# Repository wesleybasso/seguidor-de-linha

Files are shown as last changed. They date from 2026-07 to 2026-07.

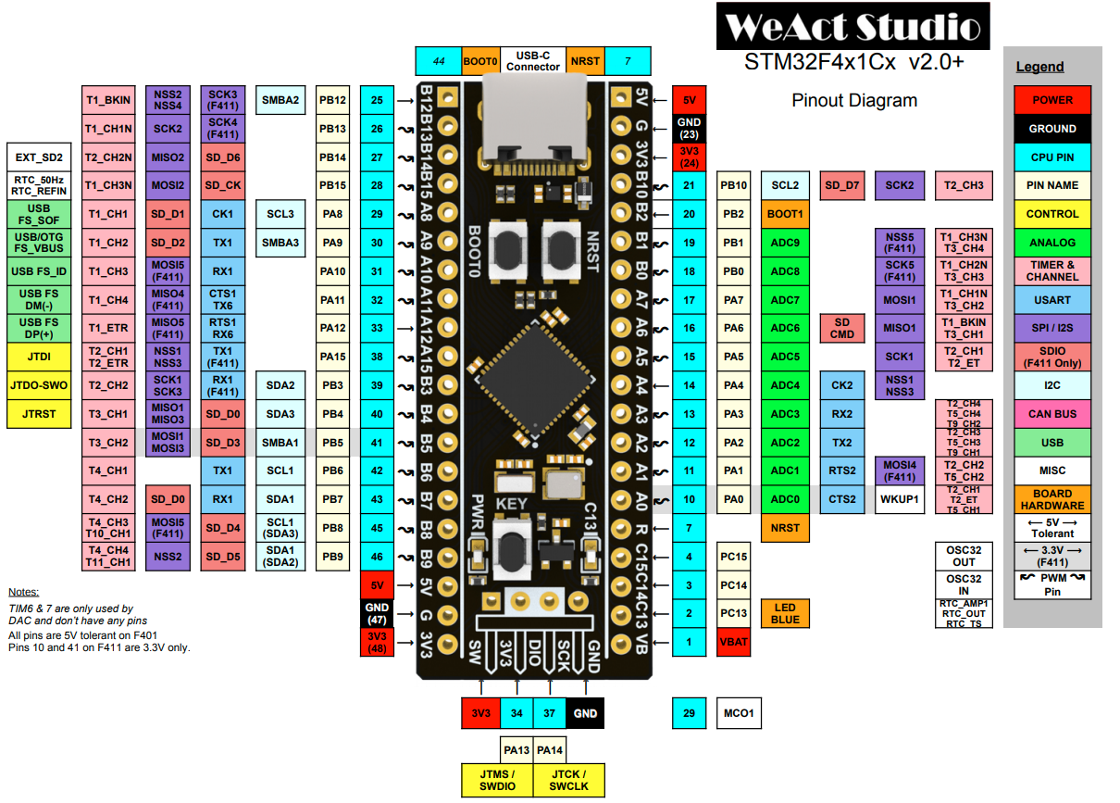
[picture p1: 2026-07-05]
STM32F411CE-Black-Pill-Board-Pinout-Diagram.png

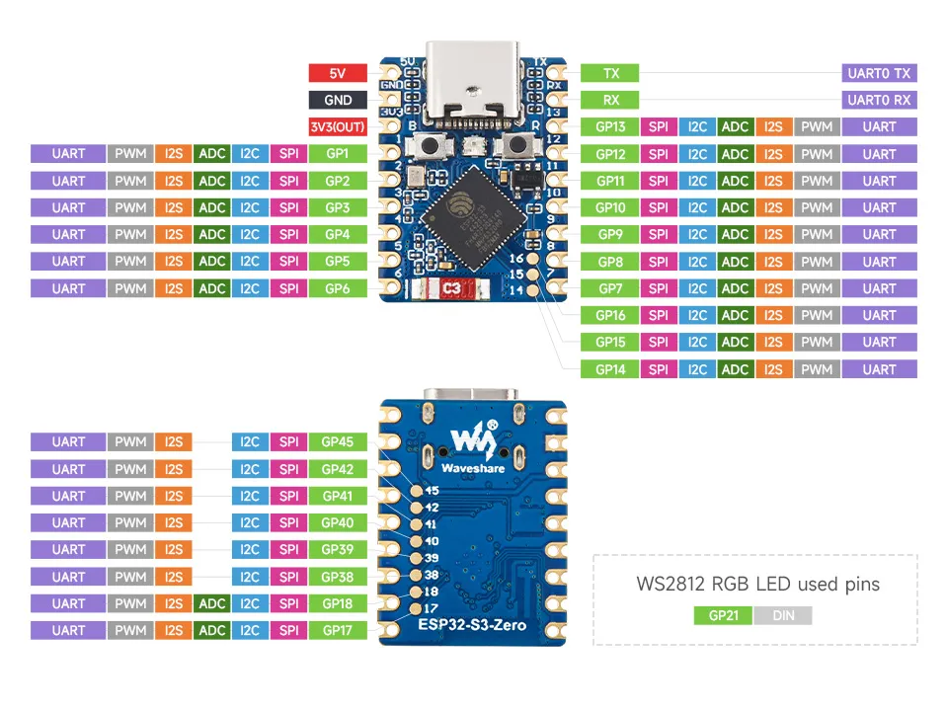
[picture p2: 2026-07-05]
ESP32-S3-Zero pin.png

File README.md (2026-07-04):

# PEGASUS Rev A0

PEGASUS e um robo seguidor de linha modular em tres placas.

- `HDB-001` Brain Board: Black Pill STM32F411, XIAO ESP32-S3/Plus, debug e conectores para o chassi.
- `HDB-100` Chassis / Power Board: LiPo 2S, chave, TB6612FNG, buck 5V, motores e succao central.
- `HDB-101` Sensor Board: placa frontal/adaptadora para sensor vermelho de 8 canais na Rev A0.

## Estrutura

- `kicad documents/`: projetos KiCad e biblioteca local de footprints placeholder.
- `docs/`: requisitos, pinagem e decisoes de engenharia.
- `firmware/`: requisitos iniciais de firmware STM32/ESP32 e protocolo UART.
- `manufacturing/`: checklist preliminar JLCPCB/PCBWay.
- `sketches/`: desenhos de arquitetura e mecanica.

## Estado Atual

Base mecanica KiCad Rev A0 criada. Ainda nao ha roteamento final, ERC/DRC final, nem Gerbers de fabricacao.

Nao enviar para fabricacao sem revisar:

- footprints reais com paquimetro;
- pinagem real da Black Pill, XIAO e modulo TB6612;
- corrente dos motores e succao;
- espacamento de bateria, motores, ventosa e empilhamento;
- DRC/ERC completo apos esquematicos e roteamento.

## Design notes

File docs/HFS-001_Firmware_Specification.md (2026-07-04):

# HFS-001 — Firmware Specification

Projeto: PEGASUS  
Revisão: A0

## 1. STM32F411

Responsável por:

- leitura A0–A7;
- leitura laterais;
- cálculo da posição da linha;
- PID;
- controle TB6612;
- controle FAN_PWM;
- comunicação UART;
- estado de segurança.

Estados:

- BOOT
- IDLE
- CALIBRATION
- READY
- RUN
- ERROR
- SAFE_STOP

## 2. ESP32-S3

Responsável por:

- telemetria;
- interface web futura;
- configuração de PID;
- log;
- comunicação USB/Wi-Fi/BLE.

Não deve controlar motores em tempo real.

## 3. Frequências sugeridas

- ADC: >= 1 kHz.
- PID: >= 1 kHz.
- Telemetria: 20–100 Hz.
- PWM motor: 20–50 kHz.
- PWM sucção:
  - MOSFET: 10–25 kHz.
  - ESC: sinal compatível com servo/ESC.

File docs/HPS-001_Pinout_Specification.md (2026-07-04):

# HPS-001 — Pinout Specification

Projeto: PEGASUS  
Revisão: A0

## 1. STM32F411 — Black Pill

### Sensores centrais

| Sinal | Pino STM32 | Função |
|---|---|---|
| A0 | PA0 | Sensor central 0 |
| A1 | PA1 | Sensor central 1 |
| A2 | PA2 | Sensor central 2 |
| A3 | PA3 | Sensor central 3 |
| A4 | PA4 | Sensor central 4 |
| A5 | PA5 | Sensor central 5 |
| A6 | PA6 | Sensor central 6 |
| A7 | PA7 | Sensor central 7 |

### Sensores laterais

| Sinal | Pino STM32 | Função |
|---|---|---|
| LAT_L | PB0 | Sensor lateral esquerdo |
| LAT_R | PB1 | Sensor lateral direito |

Observação:
Com A0–A7 + LAT_L + LAT_R, os canais ADC práticos ficam ocupados.  
Medição de bateria deve ser opcional por divisor no ESP32, ADC externo ou multiplexação futura.

### TB6612

| Sinal | Pino STM32 | Função |
|---|---|---|
| PWMA | PB8 | PWM motor esquerdo |
| AIN1 | PB10 | Direção motor esquerdo 1 |
| AIN2 | PB11 | Direção motor esquerdo 2 |
| PWMB | PB9 | PWM motor direito |
| BIN1 | PB12 | Direção motor direito 1 |
| BIN2 | PB13 | Direção motor direito 2 |
| STBY | PB14 | Standby TB6612 |

### Sucção

| Sinal | Pino STM32 | Função |
|---|---|---|
| FAN_PWM | PA8 | PWM sucção / ESC |

### UART STM32 ↔ ESP32

| Sinal | Pino STM32 |
|---|---|
| STM32_TX | PA9 |
| STM32_RX | PA10 |

Adicionar resistores série de 47Ω, se possível.

### SWD

| Função | Pino |
|---|---|
| SWDIO | PA13 |
| SWCLK | PA14 |
| NRST | NRST |
| 3V3 | 3V3 |
| GND | GND |

## 2. J1 — Brain ↔ Chassis — Sensores/Lógica

Tipo sugerido: 2x6 2.54 mm board-to-board.

| Pino | Sinal |
|-----:|---|
| 1 | 3V3 |
| 2 | GND |
| 3 | A0 |
| 4 | A1 |
| 5 | A2 |
| 6 | A3 |
| 7 | A4 |
| 8 | A5 |
| 9 | A6 |
| 10 | A7 |
| 11 | LAT_L |
| 12 | LAT_R |

## 3. J2 — Brain ↔ Chassis — Comandos/Potência

Tipo sugerido: 2x6 2.54 mm board-to-board.

| Pino | Sinal |
|-----:|---|
| 1 | VBAT_ADC opcional |
| 2 | GND |
| 3 | 5V_IN |
| 4 | GND |
| 5 | PWMA |
| 6 | AIN1 |
| 7 | AIN2 |
| 8 | PWMB |
| 9 | BIN1 |
| 10 | BIN2 |
| 11 | STBY |
| 12 | FAN_PWM |

## 4. Pendências

- Confirmar modelo exato do XIAO.
- Confirmar pinagem real do módulo TB6612.
- Definir medição de bateria.
- Definir se laterais serão analógicos ou digitais.

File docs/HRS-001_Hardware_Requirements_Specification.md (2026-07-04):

# HRS-001 — Hardware Requirements Specification

Projeto: PEGASUS  
Revisão: A0

## 1. Visão geral

O hardware é dividido em três placas:

- HDB-001 Brain Board.
- HDB-100 Chassis / Power Board.
- HDB-101 Sensor Board.

## 2. HDB-001 — Brain Board

### Função

Placa superior de lógica, controle, comunicação e debug.

### Componentes

- Black Pill STM32F411CEU6 plugável.
- XIAO ESP32-S3 ou XIAO ESP32-S3 Plus plugável.
- LEDs de status.
- Botões de boot/reset.
- Header SWD.
- Header UART debug.
- Conectores J1/J2 para chassi.
- Buck local opcional apenas para uso standalone.

### Não incluir

- TB6612.
- Motores.
- XT30.
- MOSFET de alta corrente.
- Capacitores grandes de potência.

## 3. HDB-100 — Chassis / Power Board

### Função

Placa inferior estrutural e de potência.

### Componentes

- XT30 para LiPo 2S.
- Chave geral ou chave de lógica.
- Capacitores bulk.
- Buck 5V.
- TB6612FNG.
- Conectores dos motores.
- Conector/área para sucção central.
- Furo/duto de sucção.
- Conectores J1/J2 para Brain Board.
- Conexão para Sensor Board.

## 4. HDB-101 — Sensor Board

### Função

Placa frontal de sensores.

### Rev A0

Pode ser interface para sensor comercial existente.

### Futuro

Sensor Board própria com sensores IR, resistores, filtros e conectores.

## 5. Alimentação

- Entrada: LiPo 2S.
- VBAT/VMOTOR: motores e sucção.
- 5V: lógica e Brain Board.
- 3V3: sensores e sinais lógicos.

## 6. Requisitos de segurança

- Todos os GNDs em comum.
- Corrente alta não deve passar pela Brain Board.
- Trilhas de potência largas.
- Capacitores próximos do TB6612, buck e entrada.
- Sinais analógicos afastados de motor/buck.
- Usar test points para sinais críticos.

## 7. Fabricação

- FR4.
- 1.6 mm.
- 2 camadas na Rev A0.
- Cobre 1 oz.
- Montagem manual possível.
- Silkscreen claro.

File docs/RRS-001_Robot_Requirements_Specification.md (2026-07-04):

# RRS-001 — Robot Requirements Specification

Projeto: PEGASUS  
Revisão: A0  
Autor: Wesley Mateus Basso / Hander

## 1. Objetivo

Definir os requisitos do robô antes do desenvolvimento detalhado das PCBs.

## 2. Arquitetura física

O robô usa dois andares:

- **Andar inferior:** HDB-100 Chassis / Power Board.
- **Andar superior:** HDB-001 Brain Board.
- **Frente:** HDB-101 Sensor Board.

A PCB inferior deve funcionar como parte estrutural do chassi.

## 3. Formato

O robô deve ser alongado, inspirado em seguidores de linha competitivos.

Características:

- frente estreita com régua de sensores;
- corpo central/traseiro largo;
- motores nas laterais;
- bateria baixa e centralizada;
- sucção central;
- Brain Board empilhada acima da região de controle.

## 4. Componentes mecânicos/eletrônicos principais

### Motores

- Tipo: N20.
- Rotação: 1000 rpm.
- Tensão nominal: 6V.
- Encoder: não, na Rev A0.

### Bateria

- Tipo: LiPo 2S.
- Tensão nominal: 7.4V.
- Tensão cheia: 8.4V.
- Capacidade sugerida: 450 a 850 mAh.
- Capacidade final: pendente.

### Sucção

- Um motor de sucção central.
- Tipo ainda indefinido.
- A placa deve suportar:
  - motor DC via MOSFET; ou
  - EDF/brushless via ESC.

### Sensores

- Sensor frontal vermelho tipo QTR/HY-S301/8 canais.
- Entradas A0–A7.
- Sensores laterais unitários já comprados.

## 5. Objetivos de firmware

- Loop PID: >= 1 kHz.
- Leitura de sensores: >= 1 kHz.
- PWM motores: 20 a 50 kHz se possível.
- Comunicação STM32 ↔ ESP32 por UART.
- ESP32 não deve ser necessário para o robô competir.

## 6. Prioridades

1. Funcionar.
2. Ser barato.
3. Ser fácil de consertar.
4. Validar firmware.
5. Validar mecânica.
6. Depois integrar e miniaturizar.

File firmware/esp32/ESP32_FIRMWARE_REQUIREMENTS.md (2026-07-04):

# ESP32-S3 Firmware Requirements

## Mínimo

- UART com STM32.
- Serial USB.
- Start/Stop.
- Ajuste PID.
- Telemetria.

## Futuro

- Interface web.
- BLE.
- OTA.
- Log.

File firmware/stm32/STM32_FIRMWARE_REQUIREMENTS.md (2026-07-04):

# STM32 Firmware Requirements

## Mínimo

- Piscar LED.
- Ler A0–A7.
- Ler LAT_L/LAT_R.
- Controlar TB6612.
- Controlar FAN_PWM.
- Comunicar via UART.
- SAFE_STOP.

## Arquivos sugeridos

- board_pins.h
- adc_sensors.c
- motor_tb6612.c
- fan_control.c
- pid_controller.c
- line_position.c
- uart_protocol.c
- robot_state_machine.c

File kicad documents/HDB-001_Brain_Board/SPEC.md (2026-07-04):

# HDB-001 — Brain Board

## Função

Placa superior do PEGASUS. Responsável por lógica, controle, comunicação e debug.

## Dimensões

- Alvo: 75 x 40 mm.
- 2 camadas.
- 4 furos M2/M2.5.

## Componentes

| Ref | Componente | Função |
|-----|---|---|
| U1 | Black Pill STM32F411 | Controle em tempo real |
| U2 | XIAO ESP32-S3 | Telemetria/comunicação |
| U3 | Mini360 opcional | 5V standalone |
| J1 | 2x6 board-to-board | sensores/lógica |
| J2 | 2x6 board-to-board | comandos/potência |
| J3 | SWD | debug STM32 |
| J4 | UART debug | debug serial |
| D1–D5 | LEDs | status |
| SW1/SW2 | botões | reset/boot |

## Observação

Se o 5V vier do HDB-100, U3 pode ser DNP.

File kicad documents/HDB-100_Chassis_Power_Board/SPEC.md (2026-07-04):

# HDB-100 — Chassis / Power Board

## Função

Placa inferior estrutural e de potência.

## Dimensões

- Comprimento máximo: 182 mm.
- Largura máxima: 78 mm.
- Furo central de sucção: Ø22 mm inicial.

## Componentes

| Ref | Componente | Função |
|-----|---|---|
| JBAT | XT30 | entrada LiPo 2S |
| SW_PWR | chave | liga/desliga |
| Cbulk | 470–1000uF | filtro VBAT |
| UDRV | TB6612FNG | motores |
| UBUCK | Mini360/buck | 5V |
| J_ML | motor L | saída motor esquerdo |
| J_MR | motor R | saída motor direito |
| J_FAN | fan/ESC | sucção |
| Q_FAN | MOSFET opcional | motor DC sucção |
| J1/J2 | board-to-board | Brain Board |
| JSENS | sensor board | HDB-101 |

## Observação

Um único TB6612 é suficiente para os dois motores.

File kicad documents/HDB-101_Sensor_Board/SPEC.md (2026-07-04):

# HDB-101 — Sensor Board

## Função

Placa frontal de sensores.

## Rev A0

Pode ser adaptadora do sensor vermelho comprado.

## Sinais

- A0–A7
- LAT_L
- LAT_R
- 3V3 ou 5V
- GND

## Requisitos

- Ficar na frente do robô.
- Cabo curto.
- Permitir ajuste de altura.

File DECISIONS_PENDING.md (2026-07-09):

# DECISIONS_PENDING.md - Pendencias E Travamentos PEGASUS Rev A0

Atualizado: 2026-07-08.

## P0 - Travamentos Antes De PCB Fabricavel

- Escolher ESP32 definitivo para HDB-001: Seeed XIAO ESP32-S3, XIAO ESP32-S3
  Plus ou Waveshare ESP32-S3-Zero.
- Medir com paquimetro: Black Pill, ESP32 escolhido, TB6612, Mini360, sensor
  vermelho, bateria, motores, rodas, succao/duto e conectores.
- Substituir footprints placeholder por footprints reais com pin 1, silkscreen,
  courtyard e altura.
- Criar esquematicos eletricos reais; hoje ha labels globais, mas nao circuito
  completo.
- Validar pinout real do modulo TB6612 comprado.
- Definir conectores reais de motor, fan/ESC, sensor, XT30, chave e
  board-to-board.
- Definir estrategia de GND: potencia, analogico e ponto comum.
- Confirmar se a succao Rev A0 sera fan/ESC pronto, motor DC com `Q_FAN`, ou
  apenas area mecanica sem acionamento na primeira fabricacao.
- Validar se `CBULK1` cabe perto do TB6612 sem colidir com bateria, Brain Board
  ou fixacao mecanica.

## P0 - Travamentos Antes De Bancada Com Atuadores

- Implementar transacao real de comando no ESP32: comando pendente, ACK/NACK,
  timeout, retry, RTT e ultimo erro.
- Confirmar em hardware que STOP fora da fila comum corta PWM/STBY/fan no tempo
  maximo definido.
- Integrar HAL real minima no STM32 para UART, tick e watchdog.
- Definir payload de `HARDWARE_TEST`: alvo, PWM, duracao, direcao e timeout.
- Resolver divergencia entre requisito de loop/sensores `>= 1 kHz` e
  `PEGASUS_CONTROL_HZ 500`.

## P1 - Decisoes De Sistema

- Definir medicao de bateria: divisor no STM32, divisor no ESP32, ADC externo
  ou remover `battery_mv` da promessa Rev A0.
- Definir se sensores laterais `LAT_L/LAT_R` serao analogicos ou digitais.
- Definir politica quando ESP32 some: STM32 deve parar sempre ou apenas em
  certos estados?
- Definir semantica de `ERROR_STATUS` no protocolo.
- Definir resultado esperado de calibracao na telemetria.

## P2 - Dashboard

- Manter mockup HTML como visual source e gerar versao embarcada enxuta em
  `web_ui.h`.
- Criar modo Bring-up com checklist guiado.
- Mostrar idade da telemetria, ultimo pacote, stale/timeout, ACK/NACK e RTT.
- Habilitar/desabilitar botoes conforme estado STM32.
- Expor `/api/summary` e `/api/analyze` na UI.

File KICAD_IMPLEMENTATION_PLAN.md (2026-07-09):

# KiCad Implementation Plan - PEGASUS Rev A0

Atualizado: 2026-07-08.

## Estado Atual Honesto

- HDB-001 existe como outline, posicionamento mecanico, J1/J2 conforme HPS,
  debug J3 e algumas pre-rotas de bancada.
- HDB-101 existe como adaptador Rev A0 com `JSENS` e `J1` em ordem HPS, com
  pre-rotas diretas entre os headers.
- HDB-100 existe como maquete mecanica/potencia com placeholders.
- Nenhuma placa esta liberada para Gerber final.

## Atualizacao 2026-07-06

- HDB-101 recebeu `JSENS` em ordem HPS e pre-rotas diretas para `J1`.
- HDB-001 recebeu labels de bancada para SWD/UART e pre-rotas curtas de J3
  para sinais de debug/USART do Black Pill.
- Foi criado footprint placeholder `PinHeader_1x04_2p54` para headers curtos
  de bancada.

## Atualizacao 2026-07-08

- HDB-100 recebeu placeholders explicitos para `JBAT`, `SW_PWR`, `CBULK1`,
  `J_ML`, `J_MR` e `J_FAN`.
- Foi criada a net `VBAT_RAW` para separar entrada LiPo crua de `VMOTOR`
  chaveado.
- Foram criados footprints placeholder:
  `PowerConnector_1x02_3p5`, `BulkCap_Radial_D10_P5` e
  `SlideSwitch_SPST_8x4`.
- O PCB recebeu textos de revisao para corredor `VBAT/VMOTOR`, corredor
  analogico e decisao pendente de `Q_FAN`/ESC.
- Sprint sem hardware documentado em
  `docs/OFFLINE_KICAD_SPRINT_2026-07-08.md`.

## Prioridade Atual

1. Fechar ESP32 oficial da HDB-001: XIAO ESP32-S3/Plus ou Waveshare Zero.
2. Transformar HDB-001 de schematic placeholder em schematic eletrico real.
3. Validar pad a pad do Black Pill contra HPS.
4. Roteamento completo da HDB-001 somente apos pinagem real.
5. HDB-100 continua bloqueada por XT30, chave, TB6612 real, buck, conectores,
   capacitores, fan/ESC e estrategia de GND.

## Projetos

- `HDB-001_Brain_Board`
- `HDB-100_Chassis_Power_Board`
- `HDB-101_Sensor_Board`

## Footprints Mecanicos Placeholder

| Modulo | Dimensao aproximada | Status |
|---|---:|---|
| Black Pill | 53 x 21 mm | Placeholder, precisa validar pad a pad |
| XIAO ESP32-S3 | 21 x 18 mm | Placeholder, variante ainda pendente |
| TB6612 modulo | 20 x 20 mm | Placeholder, pinout real pendente |
| Mini360 | 17 x 11 mm | Placeholder |
| Bateria LiPo | 70 x 38 x 18 mm | Placeholder mecanico |
| Ventosa | furo D22 mm | Inicial |
| XT30/conector potencia | 1x02 3.5 mm generico | Placeholder, precisa conector real |
| Chave geral | SPST 8 x 4 mm generico | Placeholder, precisa chave real |
| Capacitor bulk | radial D10 P5 | Placeholder, altura e diametro pendentes |

## HDB-001 Brain Board

Outline:

- 75 x 40 mm.
- J1/J2 na borda inferior.
- ESP32 a esquerda.
- Black Pill a direita/centro.
- SWD/UART acessiveis.
- 4 furos.

Proximos passos:

- Criar esquematico real.
- Adicionar resistores serie UART 47R.
- Adicionar LEDs e resistores.
- Adicionar reset/boot conforme modulo escolhido.
- Adicionar test points.
- So rotear depois de validar pinagem Black Pill e ESP32.

## HDB-100 Chassis / Power Board

Outline:

- Ate 182 x 78 mm.
- Furo de succao central D22 mm.
- Bateria baixa e central/traseira.
- Motores nas laterais.
- TB6612 perto dos motores.
- XT30 acessivel.
- Buck 5V.
- J1/J2 alinhados com HDB-001.

Bloqueios:

- XT30/conector real.
- Chave real.
- Capacitores bulk reais.
- Conectores reais de motor.
- Fan/ESC real.
- Pinout TB6612 real.
- Estrategia de GND e potencia.

Estado de maquete:

- `JBAT` representa entrada LiPo crua em `VBAT_RAW`.
- `SW_PWR` representa chaveamento de `VBAT_RAW` para `VMOTOR`.
- `CBULK1` fica em `VMOTOR`/`GND` perto do TB6612.
- `J_ML` e `J_MR` expõem saidas do TB6612.
- `J_FAN` expõe `VMOTOR`, `GND`, `FAN_PWM` e `5V_IN` para fan/ESC.
- `Q_FAN` segue como decisao pendente, nao como circuito real.

## HDB-101 Sensor Board

Outline:

- 90 x 18 mm.
- `JSENS` e `J1` seguem a mesma ordem HPS:
  `3V3, GND, A0-A7, LAT_L, LAT_R`.
- Pre-rotas diretas ja existem.

Proximos passos:

- Validar pinagem fisica do sensor vermelho.
- Adicionar slots/furos de ajuste de altura.
- Ajustar posicao do cabo para nao raspar na pista.

## Ordem De Implementacao

1. Validar modulo ESP32 oficial.
2. Validar Black Pill pad a pad.
3. Criar schematic real da HDB-001.
4. Roteamento HDB-001.
5. Validar sensor vermelho e finalizar HDB-101.
6. Medir componentes de potencia.
7. Criar schematic real da HDB-100.
8. Roteamento HDB-100 com net classes.
9. ERC/DRC.
10. Revisao humana.
11. Somente depois gerar Gerbers.

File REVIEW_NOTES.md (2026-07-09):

# REVIEW_NOTES.md — Revisão cruzada entre agentes

Formato: cada entrada é datada e assinada pelo agente. Ninguém edita a área
do outro; achados viram nota aqui e o dono decide.

---

## 2026-07-06 — Claude Code (revisão de firmware + achados para os outros)

### Verificação do firmware contra as especificações (área própria — corrigido)

- Parser UART, CRC8, ACK/NACK e PING/PONG conferidos contra HCP-001: OK nos
  dois lados; enums de estado STM32↔ESP32 alinhados (0–11).
- Corrigido: `HARDWARE_TEST` (0x0C) era respondido com NACK pelo STM32 —
  agora ACK apenas em IDLE/READY, com timeout de 3 s já existente na FSM.
- Corrigido: dashboard não tinha STOP sempre visível (exigência da spec) nem
  botão PING — adicionados (barra fixa + indicador STM32 online/offline).
- Adicionado: telemetria fake no HAL de bancada do STM32 (linha triangular
  varrendo S0..S7) — sem isso o dashboard mostraria só zeros na Fase 0.
- Builds validados: `pio run` OK para `esp32-s3-zero` e `xiao-esp32-s3`;
  `arm-none-eabi-gcc -fsyntax-only` OK para todos os fontes STM32.

### Para o Codex (hardware/PCB) — nada editado, só observações

- O firmware assume ADC em PA0–PA7 (frontais) + PB0/PB1 (laterais analógicos).
  Roteamento precisa manter esses canais longe do buck/motores (risco já
  listado no PEGASUS_REV_A0_PENDING_RISKS.md).
- UART fixa em PA9/PA10 (USART1). Se o roteamento da HDB-001 precisar mudar
  isso, avisar antes — o firmware referencia esses pinos em `board_pins.h`.
- FAN_PWM em PA8 (TIM1_CH1) e TB6612 em PB8–PB14: conferir conflito de
  timer/AF quando o esquemático for fechado.

### Para o ChatGPT (arquitetura/specs) — nada editado, só observações

- HPS-001 vs `board_pins.h` do STM32: consistentes hoje.
- A spec do dashboard pede "análise inteligente e sugestões automáticas";
  no firmware isso é stub (`analyzer_task` vazio). Sugiro definir na spec o
  que a Rev A0.1 realmente promete, para não inflar escopo da Fase 0.
- `TELEMETRY_BASIC` envia `battery_mv = 0` (medição de bateria indefinida —
  pendência já aberta). Quando decidirem divisor/ADC, atualizar HCP-001 se
  a semântica mudar.

---

## 2026-07-08 — Codex (hardware/PCB sem bancada fisica)

### HDB-100 - avancado como maquete KiCad, nao fabricavel

- Adicionados placeholders para `JBAT`, `SW_PWR`, `CBULK1`, `J_ML`, `J_MR` e
  `J_FAN`.
- Criada net `VBAT_RAW` para separar entrada LiPo crua de `VMOTOR` chaveado.
- Adicionados textos de revisao no PCB para corredor de potencia, corredor
  analogico e decisao pendente de `Q_FAN`/ESC.
- Nao foi gerado Gerber e a placa continua bloqueada ate medicao real.
- DRC KiCad 9.0.3 em `HDB-100_Chassis_Power_Board.kicad_pcb`: sem curto e
  sem courtyard overlap apos reposicionamento; ainda existem 54 desconexoes e
  38 warnings de placeholder/silk/texto.

### Pontos para revisao humana

- `CBULK1` pode colidir com bateria/Brain Board dependendo da altura real.
- `J_FAN` esta como header 1x04 generico; fan/ESC real pode exigir outro
  conector ou MOSFET dedicado.
- `PowerConnector_1x02_3p5` representa motor/XT30 apenas como placeholder; nao
  deve ser usado como footprint final de fabricacao.

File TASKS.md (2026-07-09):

# TASKS.md - PEGASUS Rev A0

Atualizado: 2026-07-08.

## Fase 0 - Protoboard Sem Motores

- [x] Criar estrutura do repositorio.
- [x] Criar protocolo UART comum HCP-001.
- [x] Implementar CRC8 em STM32, ESP32 e referencia Python.
- [x] Implementar parser de pacotes em STM32 e ESP32.
- [x] Implementar telemetria fake no STM32 para bancada.
- [x] Implementar dashboard minimo embarcado no ESP32.
- [x] Criar dashboard mockup separado em `docs/esp32-control-dashboard.html`.
- [x] Criar emulador de STM32 em `tools/pegasus_fake_stm32.py`.
- [x] Criar testes Python de protocolo em `tests/protocol`.
- [x] Tratar `HARDWARE_TEST` no STM32 com ACK somente em IDLE/READY.
- [x] Fazer STOP entrar na frente da fila de comandos do ESP32.
- [x] Rejeitar payload extra em comandos simples STM32.
- [x] Proteger encoder UART contra payload nulo invalido.
- [x] Fazer ARM/START/DISARM/CAL responder ACK/NACK conforme estado valido.
- [x] Portar cockpit compacto para `firmware/esp32/web/web_ui.h`.
- [x] Rastrear no ESP32 ultimo ACK/NACK/PONG, comando pendente e RTT simples.
- [x] Criar build real STM32 F411 com `build.ps1`, `Makefile` e HAL `PEGASUS_TARGET_F411`.
- [x] Criar runbook F0 de bancada com ligacao, build, dashboard e criterios de aceite.
- [ ] Implementar command manager ESP32 com ACK/NACK, timeout, retry e RTT.
- [ ] Implementar retry/timeout ativo para comando pendente no ESP32.
- [x] Mostrar no dashboard: contadores ACK/NACK/PONG, RTT e idade da telemetria.
- [ ] Adicionar mutex ou snapshot atomico para telemetry/config/log no ESP32.
- [x] Trocar validacoes STM32 para tamanho exato quando aplicavel.
- [x] Clampar PID, motor, fan e `fan_mode` antes de aplicar configuracao.
- [ ] Definir payload seguro de `HARDWARE_TEST`.
- [x] Criar HAL minima register-level: USART1 PA9/PA10, SysTick, ADC/DMA, PWM, GPIO e watchdog.
- [ ] Testar `PING/PONG` por 1000 ciclos no hardware real.
- [ ] Testar START/STOP/ARM/CALIBRATION no hardware real.
- [ ] Exibir sensores fake no dashboard via hardware real por 10 minutos.

## Fase 1 - Sensores Reais

- [ ] Ler sensores analogicos A0-A7.
- [ ] Decidir e validar LAT_L/LAT_R analogico ou digital.
- [ ] Calibrar fundo e linha.
- [ ] Normalizar sensores 0-1000.
- [ ] Validar linha perdida.
- [ ] Validar cruzamento.
- [ ] Medir ruido com buck/motores desligados e ligados.
- [ ] Resolver divergencia `>= 1 kHz` versus `PEGASUS_CONTROL_HZ 500`.

## Fase 2 - Atuadores Em Bancada

- [ ] Usar fonte limitada antes da LiPo.
- [ ] Validar 5V, 3V3, VMOTOR e GND comum.
- [ ] Validar TB6612 em standby no boot.
- [ ] Testar motores com rodas suspensas e PWM baixo.
- [ ] Medir corrente de stall com teste curto e controlado.
- [ ] Validar STOP imediato durante motor suspenso.
- [ ] Testar succao/fan/ESC isolado, sem tracao.
- [ ] Medir corrente, vibracao e temperatura da succao.

## Fase 3 - PCB Rev A0 Fabricavel

- [ ] Escolher ESP32 definitivo: XIAO ESP32-S3, XIAO ESP32-S3 Plus ou ESP32-S3-Zero.
- [ ] Medir todos os modulos com paquimetro.
- [ ] Substituir footprints placeholder por footprints reais.
- [x] Adicionar header roteado JSENS na HDB-101 para adaptador Rev A0 em ordem HPS.
- [x] Marcar J3 da HDB-001 como header de bancada SWD/UART para ESP32-S3-Zero.
- [x] Adicionar placeholders HDB-100 para JBAT, SW_PWR, CBULK1, J_ML, J_MR e J_FAN.
- [x] Separar `VBAT_RAW` de `VMOTOR` na maquete KiCad da HDB-100.
- [ ] Criar esquematico eletrico real da HDB-001.
- [ ] Ligar UART STM32 PA9/PA10 ao ESP32 definitivo.
- [ ] Definir conectores reais de J1/J2, motores, fan/ESC, sensor, XT30 e chave.
- [ ] Criar esquematico eletrico real da HDB-100.
- [ ] Conferir colisao mecanica entre bateria, CBULK1, JBAT, SW_PWR e Brain Board em impressao 1:1.
- [ ] Conferir HPS-001 contra KiCad.
- [ ] Rodar ERC/DRC.
- [ ] Fazer revisao mecanica impressa 1:1.
- [ ] Abrir Gerbers/drill em viewer externo.
- [ ] Solicitar revisao humana antes de qualquer Gerber final.

## Fase 4 - Primeira Pista

- [ ] Perfil SAFE.
- [ ] Base speed baixo.
- [ ] Succao desligada ou baixa.
- [ ] Linha reta curta.
- [ ] Curva simples.
- [ ] Logs completos no dashboard.
- [ ] Revisao de temperatura e fixacao apos cada run.

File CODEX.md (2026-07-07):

# CODEX.md - Operacao Codex no PEGASUS Rev A0

Este arquivo define como o Codex deve trabalhar neste repositorio.

## Missao

Transformar o PEGASUS Rev A0 em um projeto fabricavel e testavel, sem pular
etapas de seguranca. O foco do Codex e hardware, KiCad, fabricacao, validacao
cruzada e integracao com firmware.

## Areas De Dono

Codex pode editar diretamente:

- `kicad documents/**`
- `manufacturing/**`
- `BOM_PRELIMINARY.md`
- `KICAD_IMPLEMENTATION_PLAN.md`
- documentos de processo: `AGENTS.md`, `TASKS.md`, `TEST_PLAN.md`,
  `DECISIONS.md`, `DECISIONS_PENDING.md`, `REVIEW_NOTES.md`

Codex deve propor em `REVIEW_NOTES.md`, antes de editar diretamente:

- `firmware/stm32/**`
- `firmware/esp32/**`
- `firmware/communication/**`
- especificacoes oficiais em `docs/HPS-*`, `docs/HRS-*`, `docs/HFS-*`

## Regras Inviolaveis

- Nao gerar Gerbers finais sem revisao humana.
- Nao trocar pinagem sem atualizar HPS, firmware e HDR.
- Nao substituir Black Pill ou ESP32 plugavel por MCU SMD integrado nesta Rev A0.
- Nao tratar placeholder mecanico como footprint fabricavel.
- Nao acionar motores ou succao sem plano de teste com STOP validado.

## Prioridade Atual

Fase 0: protoboard com Black Pill STM32F411 + Waveshare ESP32-S3-Zero.

Ordem de execucao:

1. Validar UART `PING/PONG` e `ACK/NACK`.
2. Tornar comandos ESP32 transacionais, com timeout e erro visivel.
3. Integrar HAL real minima no STM32: USART1 PA9/PA10, SysTick e ring buffer.
4. Validar telemetria fake e dashboard.
5. So depois entrar em ADC real, motores suspensos e succao isolada.

## Comandos Uteis

```powershell
python -m unittest discover tests/protocol
pio run -d firmware/esp32
arm-none-eabi-gcc -std=c11 -Wall -Wextra -DSTM32F411xE -I firmware/stm32/Core/Inc -I firmware/stm32/Drivers/CMSIS/Include -I firmware/stm32/Drivers/CMSIS/Device/ST/STM32F4xx/Include -fsyntax-only firmware/stm32/Core/Src/*.c
git status --short --branch
```

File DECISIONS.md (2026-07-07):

# DECISIONS.md - Decisoes Fechadas PEGASUS Rev A0

Atualizado: 2026-07-06.

## DEC-001 - Arquitetura Em Tres Placas

PEGASUS Rev A0 usa tres placas:

- HDB-001 Brain Board: Black Pill STM32F411 e ESP32 plugavel.
- HDB-100 Chassis / Power Board: LiPo 2S, buck, TB6612, motores e succao.
- HDB-101 Sensor Board: adaptador frontal para sensor vermelho de 8 canais.

Motivo: separar logica, potencia e sensor para facilitar teste, manutencao e
iteracao barata.

## DEC-002 - Fase 0 Em Protoboard

A Fase 0 fica congelada em Black Pill STM32F411 + Waveshare ESP32-S3-Zero.
O XIAO ESP32-S3 permanece como alvo de placa oficial, mas ainda depende de
confirmacao de variante e pinagem.

## DEC-003 - STM32 E Dono Do Tempo Real

O STM32 executa leitura de sensores, maquina de estados, controle PID, motores,
succao e safety critico. O ESP32 e painel, configuracao, telemetria, perfis e
analise pos-corrida.

## DEC-004 - UART Como Contrato Entre Cerebros

ESP32 e STM32 se comunicam por UART 115200 8N1 com pacotes HCP-001, CRC8,
`ACK/NACK`, `PING/PONG` e telemetria estruturada.

## DEC-005 - STOP Tem Prioridade Absoluta

`STOP_RUN` deve estar sempre disponivel no dashboard e deve cortar atuadores no
STM32 mesmo se outros fluxos estiverem ativos.

## DEC-006 - KiCad Atual E Maquete Contratual

Os projetos KiCad atuais sao base mecanica e contratual. Eles ainda nao sao
PCB fabricavel porque usam placeholders, nao possuem esquematico eletrico real,
trilhas, vias ou zonas.

## DEC-007 - Sem Gerber Final Antes De Revisao Humana

Gerbers finais so podem existir apos footprints reais, ERC/DRC, conferencia
HPS contra KiCad, revisao mecanica 1:1 e revisao humana explicita.

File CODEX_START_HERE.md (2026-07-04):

# CODEX — START HERE

Você está implementando o projeto **PEGASUS Rev A0**, um robô seguidor de linha modular da plataforma Hander.

## Regra principal

Não tome decisões críticas de engenharia sem registrar no arquivo:

`docs/HDR-001_Engineering_Decision_Record.md`

Se algo estiver ambíguo, crie uma seção **OPEN QUESTIONS** e pare antes de gerar arquivos finais.

## Ordem obrigatória de leitura

1. `docs/RRS-001_Robot_Requirements_Specification.md`
2. `docs/HRS-001_Hardware_Requirements_Specification.md`
3. `docs/HPS-001_Pinout_Specification.md`
4. `hardware/KICAD_IMPLEMENTATION_PLAN.md`
5. `docs/HMS-001_Manufacturing_Specification.md`

## Prioridade atual

Criar projetos KiCad iniciais para:

- `hardware/HDB-001_Brain_Board/kicad/`
- `hardware/HDB-100_Chassis_Power_Board/kicad/`
- `hardware/HDB-101_Sensor_Board/kicad/`

## Saída esperada a cada etapa

Ao terminar uma etapa, responda com:

- resumo do que foi feito;
- arquivos criados/alterados;
- pendências;
- riscos;
- itens que precisam de confirmação do Wesley.

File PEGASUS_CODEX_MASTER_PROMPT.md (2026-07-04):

# CODEX MASTER PROMPT — PEGASUS REV A0

Você é um engenheiro eletrônico sênior especialista em KiCad, robótica de competição, STM32, ESP32, potência embarcada, PCBs modulares e fabricação JLCPCB/PCBWay.

Sua missão é implementar o projeto **PEGASUS Rev A0** com base nos documentos deste repositório.

## Produto

PEGASUS é um robô seguidor de linha modular, com arquitetura em três placas:

### 1. HDB-001 — Brain Board

Placa superior/cérebro.

Contém:

- Black Pill STM32F411CEU6 plugável.
- Seeed XIAO ESP32-S3 ou XIAO ESP32-S3 Plus plugável.
- LEDs de status.
- Botões.
- SWD.
- UART debug.
- Conectores J1/J2 para o chassi.

Não deve conduzir corrente alta de motor.

### 2. HDB-100 — Chassis / Power Board

Placa inferior/chassi eletrônico.

Contém:

- Entrada LiPo 2S via XT30.
- Chave.
- Capacitores de potência.
- TB6612FNG para os dois motores.
- Buck 5V.
- Conectores dos motores.
- Conector/área para sucção central.
- Conectores J1/J2 para Brain Board.
- Furo/duto central para ventosa.

### 3. HDB-101 — Sensor Board

Placa frontal.

Pode inicialmente apenas adaptar o sensor vermelho existente tipo QTR/HY-S301/8 canais.

## Restrições da Rev A0

- Barata.
- 2 camadas preferencialmente.
- Módulos plugáveis.
- Montagem manual.
- Não integrar STM32 SMD.
- Não integrar ESP32 WROOM.
- Não gerar Gerbers finais sem revisão humana.

## Estilo mecânico

Não fazer robô quadrado.

Formato desejado:

- Sensor board frontal estreita.
- Braços/longarinas até o corpo principal.
- Corpo traseiro largo para bateria, motores, sucção e potência.
- Brain Board empilhada acima do chassi com espaçadores.

## Tarefa inicial para o Codex

1. Criar estrutura KiCad dos três projetos.
2. Criar footprints mecânicos placeholder para:
   - Black Pill: 53 x 21 mm.
   - XIAO: 21 x 18 mm. Confirmar variante Plus antes de final.
   - TB6612: 20 x 20 mm.
   - Mini360: 17 x 11 mm.
   - Bateria: placeholder 70 x 38 x 18 mm.
   - Ventosa: furo inicial Ø22 mm.
3. Criar outline:
   - HDB-001: 75 x 40 mm.
   - HDB-100: até 182 x 78 mm.
   - HDB-101: ~90 x 16–20 mm.
4. Implementar conectores J1/J2.
5. Implementar labels de pinagem conforme HPS-001.
6. Gerar lista de pendências e riscos.

## Não fazer ainda

- Não gerar Gerber final.
- Não escolher motor de sucção definitivo.
- Não substituir módulos por SMD integrado.
- Não mudar pinagem sem atualizar HPS e HDR.

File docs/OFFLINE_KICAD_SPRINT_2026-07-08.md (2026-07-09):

# Offline KiCad Sprint - Ate 2026-07-13

Contexto: sem recursos fisicos disponiveis ate segunda-feira, 2026-07-13.
Trabalho permitido neste periodo: ideias, arquitetura, KiCad, revisao de docs e
preparacao de bancada. Trabalho bloqueado: medicao real, teste eletrico,
validacao mecanica 1:1 e qualquer Gerber final.

## Objetivo

Transformar a Rev A0 de maquete contratual em uma base de PCB mais discutivel,
sem fingir que ja existe placa fabricavel.

## Foco Principal

1. HDB-100: organizar arquitetura de potencia.
2. HDB-001: preparar pinagem e mecanica para o ESP32 definitivo.
3. HDB-101: manter adaptador simples para o sensor vermelho existente.
4. Documentos: manter HPS, HDR, TEST_PLAN e DECISIONS_PENDING sincronizados.

## O Que Pode Ser Feito Sem Hardware

- Posicionar placeholders mecanicos com nomes reais de funcao.
- Separar regioes: sensores analogicos, logica, motores, buck, LiPo e succao.
- Revisar se J1/J2 batem com `docs/HPS-001_Pinout_Specification.md`.
- Criar net names e comentarios para reduzir erro de revisao.
- Criar checklist de DRC/ERC e fabricacao, ainda sem gerar Gerber.
- Criar lista de medidas para fazer assim que as pecas chegarem.
- Revisar o visual do robo para manter formato de competicao: frente estreita,
  longarinas e corpo traseiro largo.

## O Que Fica Bloqueado Ate Chegar Hardware

- Confirmar dimensoes reais de Black Pill, ESP32, TB6612, Mini360, bateria,
  motores, rodas, sensor vermelho, fan/ESC, chave e conectores.
- Confirmar altura dos modulos e risco de colisao entre bateria, capacitor,
  conectores e Brain Board.
- Validar orientacao de pin 1 dos modulos.
- Validar corrente de motor e succao.
- Validar ruido dos sensores com buck/motor ligados.
- Rodar revisao impressa 1:1.

## HDB-100 - Estado Apos Este Sprint

Novos placeholders no PCB:

| Ref | Funcao | Net inicial |
|---|---|---|
| JBAT | entrada LiPo 2S / XT30 placeholder | `VBAT_RAW`, `GND` |
| SW_PWR | chave geral placeholder | `VBAT_RAW` para `VMOTOR` |
| CBULK1 | capacitor bulk 470-1000 uF placeholder | `VMOTOR`, `GND` |
| J_ML | motor esquerdo | `AOUT1`, `AOUT2` |
| J_MR | motor direito | `BOUT1`, `BOUT2` |
| J_FAN | fan/ESC/succao placeholder | `VMOTOR`, `GND`, `FAN_PWM`, `5V_IN` |

Observacao: `Q_FAN` ainda nao foi implementado como circuito real. A placa esta
marcada com `Q_FAN OR ESC DRIVER TBD` para manter a decisao visivel.

## Revisao Visual Esperada

- A frente deve continuar estreita para sensor.
- As longarinas devem levar sinais de sensor para o corpo principal.
- A traseira deve concentrar LiPo, motores, buck, TB6612, chave e succao.
- A Brain Board deve empilhar acima da HDB-100 com espacadores.
- Conectores de bateria e chave devem ficar acessiveis sem desmontar o robo.

## Lista Para Segunda-feira, 2026-07-13

- Medir todos os modulos com paquimetro.
- Fotografar frente e verso dos modulos.
- Confirmar pitch e diametro de pino dos conectores.
- Confirmar altura maxima da bateria e do capacitor bulk.
- Confirmar se fan/ESC usa 2, 3 ou 4 fios.
- Confirmar orientacao real do XT30 no chassi.
- Imprimir outline 1:1 e colocar componentes por cima.

## Regra De Ouro

Enquanto houver placeholder nao medido, Gerber final continua bloqueado.

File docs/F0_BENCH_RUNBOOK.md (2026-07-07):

# F0 Bench Runbook - PEGASUS Rev A0

Atualizado: 2026-07-06.

Objetivo: validar comunicacao, dashboard e comandos sem motores, sem succao e
sem LiPo ligada ao sistema de potencia.

## Hardware

- Black Pill STM32F411CEU6.
- ESP32-S3-Zero Waveshare para Fase 0.
- Fonte USB ou fonte de bancada limitada.
- GND comum entre STM32 e ESP32.
- Sem TB6612, sem motores, sem fan/ESC.

## Ligacao UART

| Sinal | STM32 Black Pill | ESP32-S3-Zero |
|---|---|---|
| STM32_TX | PA9 | GPIO44 / RX |
| STM32_RX | PA10 | GPIO43 / TX |
| GND | GND | GND |
| Alimentacao | USB/3V3 conforme bancada | USB |

Observacao: se possivel, usar resistores serie de 47R nas linhas UART.

## Build ESP32

```powershell
cd firmware/esp32
pio run -e esp32-s3-zero
```

Upload:

```powershell
pio run -e esp32-s3-zero -t upload
```

Dashboard:

- Wi-Fi AP: `PEGASUS_SETUP`
- Senha: `pegasus123`
- URL: `http://192.168.4.1`

## Build STM32

```powershell
cd firmware/stm32
powershell -ExecutionPolicy Bypass -File .\build.ps1
```

Saidas:

- `build/firmware.elf`
- `build/firmware.bin`

## Teste Sem STM32 Real

Usar emulador com adaptador USB-serial conectado ao ESP32:

```powershell
python tools/pegasus_fake_stm32.py COM5 --baud 115200
```

Trocar `COM5` pela porta correta.

## Sequencia De Aceite F0

1. Ligar ESP32 por USB.
2. Conectar ao AP `PEGASUS_SETUP`.
3. Abrir dashboard.
4. Confirmar que STOP aparece no topo.
5. Conectar STM32 ou fake STM32.
6. Pressionar `PING`.
7. Confirmar contador `PONG` subindo no dashboard.
8. Pressionar `ARM`; esperar `ACK`.
9. Pressionar `START` apenas quando estado permitir.
10. Pressionar `STOP`; confirmar estado seguro e PWM zero.
11. Rodar por 10 minutos com telemetria fake.

## Criterios De GO

- Sem reset do ESP32.
- Sem travamento do dashboard.
- `PING/PONG` responde.
- `ACK/NACK` aparece nos contadores.
- Comando invalido gera `NACK`.
- STOP continua disponivel e prioritario.
- Nenhum atuador real conectado.

## Criterios De NO-GO

- STM32 offline intermitente.
- Erro de CRC recorrente.
- Dashboard congela.
- STOP demora ou nao retorna.
- START aceito fora de estado valido.
- Qualquer aquecimento, queda de tensao ou reset inesperado.

## Evidencia A Registrar

Criar uma entrada em `REVIEW_NOTES.md` com:

- Data.
- Hardware usado.
- Firmware ESP32 commit/hash.
- Firmware STM32 commit/hash.
- Tempo de teste.
- Contagem de ACK/NACK/PONG.
- Resultado final: GO ou NO-GO.

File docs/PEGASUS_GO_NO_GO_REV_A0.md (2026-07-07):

# PEGASUS Go/No-Go - Rev A0

Atualizado: 2026-07-06.

Este documento define o significado de "pronto" por gate. O projeto nao deve
ser tratado como pronto para pista ou competicao enquanto os gates fisicos nao
forem vencidos com evidencia.

## Status Atual

- F0 comunicacao: GO parcial em software, NO-GO ate teste real 1000 ciclos.
- F1 sensores reais: NO-GO.
- F2 potencia sem carga: NO-GO.
- F3 motores suspensos: NO-GO.
- F4 succao isolada: NO-GO critico.
- F5 integracao suspensa: NO-GO.
- F6 primeira pista lenta: NO-GO.
- F7 pre-competicao: NO-GO.

## Gate F0 - Comunicacao Sem Motores

Para virar GO:

- `PING/PONG` real por 1000 ciclos.
- CRC invalido rejeitado.
- `ACK/NACK` em comandos validos/invalidos.
- Dashboard aberto por 10 minutos sem travar.
- STOP enfileirado com prioridade e visivel no painel.

## Gate F1 - Sensores

Para virar GO:

- Raw e normalizado 0-1000 medidos em A0-A7.
- LAT_L/LAT_R definidos como analogico ou digital.
- Ruido medido com buck, motor e fan em cenarios separados.
- Calibracao repetivel em piso real.

## Gate F2 - Potencia Sem Carga

Para virar GO:

- Fonte limitada antes de LiPo.
- 5V, 3V3 e VMOTOR medidos.
- TB6612 em standby no boot.
- PWMA/PWMB/STBY/FAN_PWM conferidos no osciloscopio.
- Nenhum atuador liga sozinho.

## Gate F3 - Motores Suspensos

Para virar GO:

- HAL STM32 real para PWM/GPIO.
- Rodas suspensas.
- STOP corta PWM/STBY/brake dentro do tempo medido.
- Sentido L/R confirmado.
- Corrente de stall medida por teste curto e controlado.
- Temperatura de TB6612 e motores registrada.

## Gate F4 - Succao Isolada

Para virar GO:

- Motor/EDF/ESC escolhido.
- Corrente e brownout medidos.
- Rotor/duto protegidos mecanicamente.
- Vibracao e temperatura registradas.
- STOP corta succao.

## Gate F5 - Integracao Suspensa

Para virar GO:

- Sequencia `ARM -> FAN_SPINUP -> RUNNING -> SAFE_STOP` com rodas no ar.
- STOP provado em todos os estados ativos.
- Logs de telemetria coerentes.
- Sem reset por ruido ou queda de tensao.

## Gate F6 - Primeira Pista Lenta

Para virar GO:

- Perfil SAFE.
- Base speed baixo.
- Succao desligada ou baixa.
- Parada segura ao perder linha.
- Revisao termica e mecanica apos cada run.

## Gate F7 - Pre-Competicao

Para virar GO:

- 5 a 10 voltas repetiveis.
- Teste com bateria cheia e meia carga.
- Logs completos.
- Temperaturas dentro da margem.
- Fixacoes mecanicas revisadas.

## Bloqueios P0

- STOP prioritario ponta a ponta ainda precisa evidencia em hardware.
- HAL STM32 real ainda nao substituiu todos os simbolos weak.
- `HARDWARE_TEST` ainda precisa payload seguro antes de acionar atuadores.
- LiPo 2S cheia exige limite formal para motores 6 V.
- `battery_mv` ainda nao e medicao real.
- TB6612 real precisa pinout, corrente e temperatura.
- Succao e o maior risco aberto.
- Frequencia `>= 1 kHz` versus `PEGASUS_CONTROL_HZ 500` precisa decisao.
- Modo competicao sem ESP32 precisa politica fechada.
- PCB ainda depende de footprints reais, ERC/DRC e revisao humana.

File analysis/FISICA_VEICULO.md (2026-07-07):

# MODELO FÍSICO NUMÉRICO DO ROBÔ PEGASUS

**Data:** 2026-07-06  
**Categoria:** Seguidor de linha Pro  
**Hardware:** STM32F411 + TB6612FNG + N20 1000rpm + sucção central

---

## 1. ORÇAMENTO DE MASSA

### Componentes (estimativa realista)

| Componente | Massa (g) |
|---|---|
| Brain PCB (STM32F411) | 8 |
| Chassis/Power PCB (TB6612FNG) | 15 |
| Sensor PCB (barra + laterais) | 10 |
| Bateria LiPo 2S 400mAh | 35 |
| 2× Motor N20 1000rpm | 24 |
| 2× Suportes motor | 8 |
| 2× Rodas 25mm (silicone) | 12 |
| 2× Rodas locas traseiras 18mm | 8 |
| Ventoinha/EDF 35mm | 18 |
| ESP32-S3 (MCU secundário) | 6 |
| Parafusos + spacers + conectores | 12 |
| Fios + pequenos componentes | 8 |
| Saia duto (PLA 2mm) | 15 |
| **TOTAL REALISTA** | **179 g** |

### Meta Agressiva (140 g)

Estratégia de redução:
- Remover ESP32, usar só STM32: −6 g
- Reduzir barra sensores (6 em vez de 8): −2 g
- Rodas mais leves (PLA): −5 g
- Duto + saia otimizado: −8 g
- Parafusos: só necessários: −4 g
- **Subtotal com cortes:** 154 g

**Diferença meta vs realista:** −14 g (margem de segurança para componentes reais)

### Recomendação

- **Alvo de produção:** 155−165 g
- **Onde cortar se necessário:** reduzir PCB (mais compacta) e otimizar saia (design CAD com FEA)

---

## 2. MOTOR E TRANSMISSÃO

### Especificações N20 (Pololu/genérico)

| Parâmetro | Valor |
|---|---|
| Tensão nominal | 6.0 V |
| RPM nominal (no-load) | 1000 rpm |
| Torque no stall | 0.9 kg·cm = 0.00882 N·m |
| Corrente stall | 1.6 A |
| Corrente no-load | 0.1 A |
| PWM máx (emular 6V @ 7.4V) | ~71% |

### Análise por Diâmetro de Roda

Para **massa = 179 g = 0.179 kg** e força trativa máxima = torque_stall / raio × 2 rodas:

| Ø (mm) | V_max (m/s) | F_tração (N) | a_inicial (m/s²) |
|---|---|---|---|
| 22 | 1.152 | 0.160 | 0.90 |
| 25 | 1.309 | 0.141 | 0.79 |
| **32** | **1.676** | **0.110** | **0.62** |

**Recomendação:** Ø = **32 mm** (silicone)
- Velocidade máxima teórica: **1.68 m/s**
- Melhor compromisso velocidade × aceleração para velocidades alvo (1.3−2.5 m/s)

---

## 3. DOWNFORCE POR SUCÇÃO

### Geometria de Vácuo

- Chassis: 180 × 70 mm
- Área nominal: 12,600 mm²
- Área efetiva (70% eficiência duto): **8,820 mm² = 88.2 cm² = 0.00882 m²**

### Downforce para Diferentes Ventoinhas

| Tipo | ΔP (Pa) | Downforce (gf) | Observação |
|---|---|---|---|
| Ventoinha 35mm pequena | 300 | 270 | Mínimo viável |
| Ventoinha 40mm padrão | 600 | 540 | |
| **Mini EDF 40mm** | **1500** | **1349** | **Recomendado** |
| EDF 50mm | 3000 | 2698 | Overkill, peso extra |

**Fórmula usada:** Downforce (N) = ΔP × A_efetiva  
Conversão: 1 N ≈ 101.97 gf

### Aceleração Lateral (sem escorregamento)

**Coeficiente de atrito pneu silicone:** μ = 0.9

| Cenário | a_lat (m/s²) |
|---|---|
| SEM sucção (só peso) | **8.83** |
| COM EDF 40mm (1500 Pa, +950 gf) | **12.15** |
| Ganho de aderência | **+37.6%** |

### Velocidade Máxima em Curva

**Critério:** v_max = √(a_lat × R)

| Raio (cm) | V_max SEM (m/s) | V_max COM (m/s) | Ganho |
|---|---|---|---|
| 10 | 0.94 | 1.10 | +17% |
| 20 | 1.33 | 1.56 | +17% |
| 30 | 1.63 | 1.91 | +17% |
| 50 | 2.10 | 2.47 | +17% |

---

## 4. LIMITE SENSORIAL

### Critério de Seguimento

- Barra sensores: 72 mm úteis (8 sensores × 9 mm espaçamento)
- Linha padrão: 19 mm
- Deslocamento lateral máximo por ciclo: **< 36 mm** (metade da barra)

### Distância Percorrida por Ciclo

**T = 1/f (período de controle)**

| Frequência | Período | Dist/ciclo @ 1 m/s | Dist/ciclo @ 2 m/s | Dist/ciclo @ 3 m/s |
|---|---|---|---|---|
| 500 Hz | 2.0 ms | 2.0 mm | 4.0 mm | 6.0 mm |
| 1000 Hz | 1.0 ms | 1.0 mm | 2.0 mm | 3.0 mm |

**Conclusão:** Ambas as frequências fornecem tempo suficiente para reação. 1 kHz oferece margem maior.

### Velocidade Máxima por Raio de Curva

**Distância olhada adiante = L_sensor (distância sensores ao eixo)**

Para L = 80 mm (configuração recomendada) e resposta de controle adequada:

- **Fase 1 (sem sucção):** V_max = 1.3 m/s em R > 20 cm
- **Fase 2 (com sucção):** V_max = 2.5 m/s em R > 30 cm

**Razão:** Aceleração lateral máxima com sucção permite maior velocidade em curvas maiores.

---

## 5. GEOMETRIA RECOMENDADA

### Placa HDB-100 (182 × 78 mm)

**Verdict:** Aceitável, não é muito grande.

Comparação com chassis típicos de seguidor de linha:
- Mini-robôs: ~150 × 60 mm
- Pro (tipo PEGASUS): 180 × 75 mm ← nossa faixa
- Large: > 200 × 100 mm

### Disposição Física

| Parâmetro | Recomendação | Justificativa |
|---|---|---|
| **Wheelbase** (sensores → eixo) | 70−80 mm | Tempo mínimo para reação em curvas < 30 cm |
| **Track width** (entre rodas) | 65−75 mm | Estabilidade em curvas fechadas; limite de chassis |
| **Posição CG (Y)** | 50−60 mm do eixo traseiro | Centro de massa em Y (ao longo do comprimento) |
| **Posição bateria** | Traseira, baixa | Reduz pitch durante aceleração/frenagem |
| **Posição ventoinha/EDF** | Central, inferior | Maximiza eficiência duto; minimiza perturbação CG |

### Estimativa CG

Para massa 179 g distribuída:
- Brain + Chassis PCB: ~40 g em Y ≈ 30 mm
- Sensores: ~10 g em Y ≈ 10 mm (frente)
- Motores + rodas: ~32 g em Y ≈ −20 mm (eixo)
- Bateria: ~35 g em Y ≈ 60 mm (traseira)
- Demais: ~62 g distribuído

**CG esperado:** ~40−50 mm do eixo traseiro (estável para tração diferencial)

---

## 6. TABELA-RESUMO FINAL

| Parâmetro | Alvo | Justificativa |
|---|---|---|
| **Massa total** | 155−165 g | Realista com componentes comerciais; meta agressiva possível com otimização CAD |
| **Diâmetro roda** | 32 mm (silicone) | Velocidade máxima 1.68 m/s; melhor torque e aceleração |
| **Velocidade Fase 1** | 1.3 m/s | SEM sucção; margens seguras em curvas R > 20 cm |
| **Velocidade Fase 2** | 2.0−2.5 m/s | COM EDF 40mm; acel. lateral até 12.15 m/s² |
| **Downforce alvo** | EDF 40mm @ 1500 Pa | Downforce ≈ 950 gf; ganho +37.6% em aderência |
| **Raio mínimo Fase 1** | ~20 cm @ 1.3 m/s | v_max = √(8.83 × 0.2) = 1.33 m/s |
| **Raio mínimo Fase 2** | ~30 cm @ 2.5 m/s | v_max = √(12.15 × 0.3) = 1.91 m/s (margem) |
| **Loop controle** | 500 Hz (produção) → 1 kHz (otimização) | Período 2 ms → 1 ms garante reação a curvas fechadas |
| **Wheelbase** | 70−80 mm | Tempo resposta ~5−6 ms; suficiente para seguir R > 20 cm |
| **Track width** | 65−75 mm | Compromisso estabilidade vs tamanho chassis |

---

## PREMISSAS E INCERTEZAS

### O Que Precisa Ser Medido na Bancada

1. **Massa Real dos Componentes**
   - Cada PCB: variam de ±2 g com soldagem
   - Bateria 2S: 30−40 g conforme capacidade real
   - **Ação:** Pesar montagem completa antes de testes dinâmicos

2. **Coeficiente de Atrito (μ)**
   - Pneu silicone em piso preto (pista padrão): **0.8−1.2**
   - Variação com temperatura, desgaste de pneu
   - **Ação:** Teste em pista: medir aceleração lateral máxima com IMU (ax, ay)

3. **ΔP Real da Ventoinha/EDF**
   - Especificação vs real: ±20% típico
   - Efeito da saia/duto: perda 15−30% sem design otimizado
   - **Ação:** Manômetro na entrada duto; medir em operação @7.4V e PWM ajustado

4. **Velocidade Angular Real dos Motores**
   - Carga (atrito mecânico + downforce) reduz RPM
   - PWM @ 71% pode reduzir 5−10% vs nominal 6V
   - **Ação:** Encoder ou câmera de alta velocidade; cronometrar volta de teste

5. **Aceleração Lateral vs Velocidade (curva de aderência)**
   - Modelo linear (μ × g) é aproximação
   - Pneu silicone tem breakdown não-linear > 1.2 m/s² lateral
   - **Ação:** Teste em arco de raio fixo, variar velocidade, medir slip com visão

6. **Resposta de Controle (jitter, latência real)**
   - Latência STM32: ~1−2 ms leitura sensores + processamento
   - Verificar 500 Hz vs 1 kHz em pista: qual diferença real?
   - **Ação:** Data logging com timestamp; analisar frequência de correção efetiva

### Hipóteses Simplificadoras Neste Modelo

- **Dinâmica de motor:** modelo linear (torque = constante até stall). Real: leve queda não-linear com RPM
- **Atrito pneu:** coef. constante μ = 0.9. Real: varia com carga normal, slipe, temperatura
- **Duto:** eficiência 70%. Pode ser 60−80% conforme design real
- **Resposta de controle:** negligenciado delay. Real: ~3−5 ms no loop completo
- **Distribuição de peso:** estimada por componente. Pode variar ±10% com soldagem/layout real

---

## CONCLUSÃO

O robô PEGASUS em massa 155−165 g com diâmetro de roda 32 mm e EDF 40mm é viável para:

- **Fase 1:** 1.3 m/s em curvas > 20 cm (seguidor puro, sem sucção)
- **Fase 2:** 2.0−2.5 m/s em curvas > 30 cm (com sucção central)

Velocidades alvo excedem os 2 m/s esperados em campeonatos RoboChallenge (line-speed típico: 1.5−2.5 m/s para Pro).

**Próximas etapas:**
1. CAD detalhado com FEA para validar CG e rigidez
2. Montagem prototipo com pesagem real
3. Testes bancada: μ, ΔP, resposta motores
4. Calibração loop de controle em pista padrão

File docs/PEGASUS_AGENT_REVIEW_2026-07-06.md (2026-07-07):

# PEGASUS Agent Review - 2026-07-06

Relatorio consolidado dos quatro agentes criados para revisar o projeto em
paralelo. Nenhum agente alterou arquivos; todos trabalharam em modo de analise.

## Firmware Core

Validacao executada:

- `python -m unittest discover tests/protocol` passou com 12 testes.

Achados criticos:

- O ESP32 ainda nao trata comando como transacao real. `/api/command` responde
  `queued`, mas nao confirma ACK/NACK, timeout, retry ou erro final.
- `ACK/NACK/PONG` chegam ao ESP32 como pacotes comuns; falta correlacionar com
  o comando enviado.
- HAL STM32 ainda e mock/fraca para UART, ADC, PWM, GPIO e watchdog.
- `HARDWARE_TEST` so entra em estado e espera timeout; ainda nao testa motor,
  fan, sensor ou LED.
- Dados compartilhados no ESP32 precisam de mutex ou snapshot atomico.
- Validacao STM32 deve preferir tamanho exato de payload e clamp de faixa.
- `battery_mv` e `pid_correction` ainda podem parecer reais no dashboard, mas
  sao incompletos.

Proximas tarefas sugeridas:

1. Criar command manager ESP32 com ACK/NACK, timeout, retry e ultimo erro.
2. Tornar STOP prioritario fora da fila comum.
3. Criar HAL minima STM32Cube com USART1 PA9/PA10.
4. Definir payload seguro de `HARDWARE_TEST`.
5. Adicionar testes dos parsers C/C++ reais, nao apenas da referencia Python.

## Hardware / KiCad

Achados criticos:

- KiCad atual nao e PCB fabricavel: nao ha trilhas, vias ou zonas.
- Esquematicos ainda nao sao eletricos completos.
- Footprints sao placeholders e nao provam numeracao fisica.
- HDB-001 ainda nao liga UART STM32 PA9/PA10 ao ESP32 escolhido.
- HDB-100 ainda falta XT30 real, chave, capacitores, conectores de motor,
  fan/ESC, protecao e poligonos de potencia.
- TB6612 segue com pinout pendente.
- A escolha XIAO ESP32-S3/Plus versus ESP32-S3-Zero precisa ser fechada.

Proximas tarefas sugeridas:

1. Fechar ESP32 definitivo.
2. Medir todos os modulos com paquimetro.
3. Criar footprints reais antes de roteamento.
4. Fazer HDB-001 eletrica real primeiro.
5. Fazer revisao mecanica impressa 1:1 antes de fabricar.

## Dashboard / UX

Pontos fortes:

- Mockup separado tem boa hierarquia operacional.
- STOP e status ficam em destaque.
- Visual escuro, cinza, laranja e branco combina com bancada/corrida.

Riscos:

- Mockup ainda usa dados fake e animacao local.
- UI embarcada ainda mostra JSON cru demais.
- Falta fluxo guiado de bancada.
- Falta feedback confiavel de comando: ACK/NACK, timeout, RTT, ultimo pacote.
- Controles perigosos precisam ser habilitados conforme estado STM32.

Proximas tarefas sugeridas:

1. Usar o mockup como fonte de design, nao copiar 31 KB direto para `web_ui.h`.
2. Criar modo Bring-up.
3. Mostrar idade da telemetria e link stale/offline.
4. Expor `/api/summary` e `/api/analyze` na UI.
5. Minificar e, se necessario, servir gzip em `PROGMEM`.

## Validacao / Safety

Achados criticos:

- Antes de atuadores, validar PING/PONG, CRC e dashboard por tempo continuo.
- Antes de motores, usar fonte limitada.
- Antes de pista, testar motores suspensos.
- Succao/EDF/ESC e o maior risco mecanico e eletrico.
- Resolver divergencia entre requisito `>= 1 kHz` e `PEGASUS_CONTROL_HZ 500`.

Plano sugerido:

- F0: protoboard sem motores.
- F1: sensores.
- F2: potencia sem carga.
- F3: motores suspensos.
- F4: succao isolada.
- F5: integracao suspensa.
- F6: primeira pista lenta.
- F7: pre-competicao.

## Conclusao

O projeto ja tem espinha dorsal: specs, firmware base, protocolo, dashboard
mockup, KiCad mecanico e testes iniciais. O salto para "ouro" nao e adicionar
mais coisa solta; e fechar contratos observaveis: UART confiavel, STOP
prioritario, footprints reais, testes por fase e decisoes P0 resolvidas.

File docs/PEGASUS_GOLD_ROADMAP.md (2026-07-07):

# PEGASUS Gold Roadmap - Rev A0

Atualizado: 2026-07-06.

Objetivo: organizar o projeto como uma equipe de engenharia real, com times,
contratos, gates e entregas verificaveis.

## Equipes

### Time 1 - Firmware Tempo Real

Dono: Claude Code.

Escopo:

- STM32 state machine.
- Sensores, PID, motores, succao e safety.
- HAL real STM32Cube.
- Testes unitarios STM32.

Entregas proximas:

- HAL minima com USART1 PA9/PA10 e tick real.
- Validacao de payload com tamanho exato e clamp de faixa.
- `HARDWARE_TEST` seguro e parametrizado.

### Time 2 - ESP32 Dashboard E Telemetria

Dono: Claude Code, com revisao UX.

Escopo:

- Web server ESP32.
- Dashboard.
- Gerenciador de comandos.
- Perfis, NVS e analise pos-corrida.

Entregas proximas:

- ACK/NACK transacional.
- STOP prioritario.
- UI com estado do link, RTT, ultimo erro e gating por estado STM32.

### Time 3 - Hardware E KiCad

Dono: Codex.

Escopo:

- HDB-001, HDB-100, HDB-101 no KiCad.
- Footprints reais.
- DRC/ERC.
- BOM e fabricacao.

Entregas proximas:

- Escolher ESP32 definitivo da placa oficial.
- Criar HDB-001 eletrica real antes de roteamento.
- Substituir placeholders por footprints conferidos.

### Time 4 - Validacao E Safety

Dono: Codex + revisao humana.

Escopo:

- Plano de testes.
- Riscos eletricos/mecanicos.
- Checklist de bancada.
- Checklist pre-JLCPCB/PCBWay.

Entregas proximas:

- Executar F0 sem motores.
- Travar Gerbers enquanto placeholders existirem.
- Definir criterios de go/no-go por fase.

### Time 5 - Arquitetura E Produto

Dono: ChatGPT / humano.

Escopo:

- Requisitos oficiais.
- Pinagem HPS.
- Decisoes HDR.
- Estrategia de corrida.

Entregas proximas:

- Resolver decisoes pendentes P0.
- Manter docs sincronizados com firmware e KiCad.
- Definir escopo realista da Rev A0.1.

## Plano De Ataque Das Proximas 5 Horas

1. Congelar Fase 0: ESP32-S3-Zero + Black Pill + UART + GND comum.
2. Rodar testes de protocolo Python e builds ESP32/STM32.
3. Registrar riscos P0 em `DECISIONS_PENDING.md`.
4. Transformar matriz de validacao em `TEST_PLAN.md`.
5. Revisar dashboard mockup e manter separado do firmware embarcado.
6. Criar gate oficial: sem Gerber final antes de footprint real + ERC/DRC.
7. Commitar e enviar o pacote de coordenacao para GitHub.

## Gates

### Gate A - Bancada Sem Atuadores

Pode passar quando:

- `PING/PONG` passa por 1000 ciclos.
- Dashboard mostra STM32 online/offline corretamente.
- Telemetria fake roda por 10 minutos.
- STOP envia comando prioritario.

### Gate B - Atuadores Suspensos

Pode passar quando:

- Fonte limitada em uso.
- Motores no ar.
- STOP testado antes de START.
- Corrente e temperatura medidas.
- `HARDWARE_TEST` tem payload e timeout seguros.

### Gate C - PCB Fabricavel

Pode passar quando:

- ESP32 definitivo escolhido.
- Footprints reais validados com paquimetro.
- Esquematico eletrico completo.
- ERC/DRC limpos ou justificados.
- Revisao mecanica 1:1 feita.
- Gerbers abertos em viewer externo.

## Estado Honesto Hoje

O projeto esta acima de uma ideia: ja tem arquitetura, specs, firmware base,
dashboard mockup, protocolo, testes Python e KiCad mecanico.

Ainda nao esta pronto para fabricar nem para atuar motores reais sem bancada
controlada. O caminho para ficar forte e fechar os contratos de UART, safety,
footprints e testes antes de acelerar.

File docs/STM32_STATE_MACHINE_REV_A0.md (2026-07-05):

# PEGASUS Rev A0 - Maquina de Estados STM32

Documento: HFS-STM32-SM-001  
Revisao: A0.1  
Responsavel: Wesley Mateus Basso / Hander  
Escopo: firmware STM32F411 Black Pill, piloto em tempo real do robo PEGASUS.

## 1. Objetivo

Este documento especifica a maquina de estados principal do STM32 no PEGASUS Rev A0.

O STM32 e o controlador de tempo real. Ele deve:

- ler sensores;
- detectar linha, cruzamento e marcadores laterais;
- executar PD/PID;
- controlar TB6612;
- controlar succao;
- aplicar seguranca;
- enviar telemetria ao ESP32;
- aceitar comandos do ESP32.

O ESP32 nao executa PID, nao gera PWM real e nao decide seguranca critica.

## 2. Visao Geral

```text
BOOT
  |
  v
SELF_TEST
  |
  v
IDLE
  |\
  | \-- CALIBRATION --> READY
  |                    |
  |                    v
  +-----------------> ARMED
                         |
                         v
                    FAN_SPINUP
                         |
                         v
                      RUNNING
       +-----------------+-----------------+----------------+
       |                 |                 |                |
       v                 v                 v                v
   CROSSING         CURVE_LEFT        LINE_LOST       FINISH_DETECTED
       |                 |                 |                |
       v                 v                 v                v
    RUNNING          RUNNING       RUNNING/SAFE_STOP    SAFE_STOP

Qualquer estado -- STOP/falha recuperavel --> SAFE_STOP
Qualquer estado -- falha critica -----------> ERROR
SAFE_STOP -- DISARM/CLEAR/RESET ------------> IDLE
```

## 3. Prioridade de Decisao Durante Corrida

Dentro de `RUNNING`, a prioridade deve ser:

```text
1. STOP manual ou emergencia
2. falha critica
3. cruzamento frontal
4. linha perdida
5. LAT_R valido = fim/parada
6. LAT_L valido = curva esquerda
7. seguimento normal por PD/PID
```

Essa ordem evita que um cruzamento largo seja confundido com marcador lateral.

## 4. Regras Fundamentais

### 4.1 Cruzamento tem prioridade sobre laterais

Se os sensores frontais detectarem cruzamento:

```c
left_curve_valid = false;
right_marker_valid = false;
```

Logo:

```c
right_marker_valid = lat_r_active && !crossing_detected;
left_curve_valid   = lat_l_active && !crossing_detected;
```

### 4.2 STOP tem prioridade absoluta

`STOP_RUN`, botao fisico futuro, watchdog interno ou falha critica devem cortar a corrida.

```text
qualquer estado -> SAFE_STOP ou ERROR
```

### 4.3 O robo nao depende do ESP32 para correr

Depois de armado e iniciado, o STM32 deve conseguir manter a corrida usando a configuracao ja recebida.

Em modo bancada, pode existir:

```c
stop_on_esp_timeout = true;
```

Em modo competicao, recomendacao inicial:

```c
stop_on_esp_timeout = false;
```

## 5. Estados

## 5.1 BOOT

### Funcao

Ligar o sistema em condicao segura.

### O que faz

- inicializa clock;
- inicializa GPIO;
- inicializa ADC;
- inicializa DMA;
- inicializa timers;
- inicializa PWM;
- inicializa UART;
- inicializa watchdog;
- carrega configuracao;
- coloca motores em zero;
- coloca TB6612 em standby;
- desliga succao;
- zera variaveis de controle.

### Saidas

```text
BOOT -> SELF_TEST
```

Condicao:

```text
inicializacao basica terminou
```

### Falhas

```text
BOOT -> ERROR
```

Condicoes possiveis:

- clock falhou;
- ADC nao inicializou;
- timer PWM nao inicializou;
- configuracao corrompida sem fallback.

## 5.2 SELF_TEST

### Funcao

Conferir se o robo pode operar.

### O que faz

- verifica configuracao;
- verifica ADC;
- verifica timers;
- verifica UART;
- verifica watchdog;
- verifica se sensores tem leitura plausivel;
- verifica bateria, se `VBAT_ADC` existir;
- verifica se ha calibracao salva.

### Saidas

```text
SELF_TEST -> IDLE
```

Condicao:

```text
sistema basico OK
```

```text
SELF_TEST -> ERROR
```

Condicoes:

- configuracao invalida;
- ADC falhando;
- sensor obrigatorio morto;
- falha de hardware critica;
- bateria critica.

## 5.3 IDLE

### Funcao

Estado parado, seguro e aguardando comando.

### O que faz

- motores desligados;
- TB6612 desabilitado;
- succao desligada;
- PID resetado;
- aceita comandos do ESP32;
- permite iniciar calibracao;
- permite teste de hardware;
- envia telemetria basica.

### Saidas

```text
IDLE -> CALIBRATION
```

Condicao:

```text
ESP32 envia CALIBRATION_START
```

```text
IDLE -> READY
```

Condicao:

```text
calibracao valida ja existe
```

```text
IDLE -> HARDWARE_TEST
```

Condicao:

```text
ESP32 envia HARDWARE_TEST
```

```text
IDLE -> ERROR
```

Condicao:

```text
falha critica detectada
```

## 5.4 CALIBRATION

### Funcao

Medir fundo e linha para calibrar os sensores.

### O que faz

- coleta `min` e `max` dos sensores `A0..A7`;
- coleta `min` e `max` de `LAT_L`;
- coleta `min` e `max` de `LAT_R`;
- calcula range de cada sensor;
- detecta sensor com contraste baixo;
- calcula thresholds iniciais;
- mantem motores desligados;
- mantem succao desligada;
- envia progresso ao ESP32.

### Regra de qualidade

```c
range = sensor_max - sensor_min;
sensor_fault = range < SENSOR_MIN_RANGE;
```

### Saidas

```text
CALIBRATION -> READY
```

Condicoes:

- ESP32 envia `CALIBRATION_STOP`;
- ranges sao validos;
- sensores principais passaram.

```text
CALIBRATION -> IDLE
```

Condicao:

```text
calibracao cancelada
```

```text
CALIBRATION -> ERROR
```

Condicoes:

- sensor critico com range muito baixo;
- ADC falhou;
- timeout de calibracao.

## 5.5 READY

### Funcao

Robo calibrado, mas ainda nao armado.

### O que faz

- motores desligados;
- succao desligada;
- aceita ajuste de PID;
- aceita ajuste de PWM dos motores;
- aceita ajuste de succao;
- aceita nova calibracao;
- aceita comando `ARM`.

### Saidas

```text
READY -> ARMED
```

Condicao:

```text
ESP32 envia ARM
```

```text
READY -> CALIBRATION
```

Condicao:

```text
ESP32 envia CALIBRATION_START
```

```text
READY -> IDLE
```

Condicoes:

- reset;
- cancelamento;
- clear manual.

```text
READY -> ERROR
```

Condicao:

```text
falha critica
```

## 5.6 ARMED

### Funcao

Robo pronto para largar, mas ainda parado.

### O que faz

- motores continuam em zero;
- TB6612 pode ficar em standby;
- succao pode ficar desligada;
- monitora comando de start;
- monitora `LAT_R` como marcador de largada, se configurado.

### Saidas

```text
ARMED -> FAN_SPINUP
```

Condicao 1:

```text
ESP32 envia START_RUN
```

Condicao 2:

```c
lat_r_active && !crossing_detected
```

```text
ARMED -> READY
```

Condicao:

```text
ESP32 envia DISARM
```

```text
ARMED -> SAFE_STOP
```

Condicoes:

- `STOP_RUN`;
- emergencia;
- falha recuperavel.

```text
ARMED -> ERROR
```

Condicao:

```text
falha critica
```

## 5.7 FAN_SPINUP

### Funcao

Subir succao antes de acionar motores.

### O que faz

- liga succao em `fan_pwm_start`;
- espera `fan_start_delay_ms`;
- mantem motores em zero;
- mantem TB6612 sem tracionar.

### Saidas

```text
FAN_SPINUP -> RUNNING
```

Condicao:

```text
tempo fan_start_delay_ms terminou
```

```text
FAN_SPINUP -> SAFE_STOP
```

Condicoes:

- `STOP_RUN`;
- watchdog;
- falha;
- emergencia.

## 5.8 RUNNING

### Funcao

Estado principal de corrida.

### O que faz a cada ciclo de controle

- captura snapshot dos ADCs;
- filtra sensores;
- normaliza sensores para `0..1000`;
- calcula `front_sum`;
- calcula sensores ativos;
- calcula sensores fortemente ativos;
- calcula `first_active`;
- calcula `last_active`;
- calcula `span`;
- calcula posicao da linha;
- calcula erro;
- detecta cruzamento;
- detecta `LAT_L`;
- detecta `LAT_R`;
- detecta linha perdida;
- executa PD/PID;
- atualiza PWM dos motores;
- mantem succao em `fan_pwm_run`;
- envia telemetria.

### Saidas

```text
RUNNING -> CROSSING
```

Condicao:

```c
crossing_detected == true
```

```text
RUNNING -> LINE_LOST
```

Condicao:

```c
line_lost_confirmed == true
```

```text
RUNNING -> FINISH_DETECTED
```

Condicao:

```c
right_marker_valid && run_time_ms > finish_min_run_time_ms
```

Onde:

```c
right_marker_valid = lat_r_active && !crossing_detected;
```

```text
RUNNING -> CURVE_LEFT
```

Condicao:

```c
left_curve_valid == true
```

Onde:

```c
left_curve_valid = lat_l_active && !crossing_detected;
```

```text
RUNNING -> SAFE_STOP
```

Condicoes:

- `STOP_RUN`;
- emergencia;
- bateria critica;
- timeout de busca;
- falha recuperavel.

```text
RUNNING -> ERROR
```

Condicao:

```text
falha critica nao recuperavel
```

## 5.9 CROSSING

### Funcao

Atravessar cruzamento sem confundir marcadores laterais.

### O que faz

- ignora `LAT_L`;
- ignora `LAT_R`;
- evita contar largada/fim;
- evita contar curva;
- mantem trajetoria;
- usa erro ponderado se ainda houver informacao;
- se os sensores saturarem, pode usar erro zero ou ultimo erro valido;
- congela integral do PID.

### Regra principal

```c
if (crossing_detected) {
    left_curve_valid = false;
    right_marker_valid = false;
}
```

### Saidas

```text
CROSSING -> RUNNING
```

Condicao:

```c
crossing_detected == false
```

Depois de sair:

```text
ignorar laterais por lateral_lockout_after_crossing_ms
```

Valor inicial sugerido:

```text
50 ms a 150 ms
```

```text
CROSSING -> SAFE_STOP
```

Condicoes:

- `STOP_RUN`;
- emergencia;
- falha.

## 5.10 CURVE_LEFT

### Funcao

Tratar marcador lateral esquerdo de curva.

### Entrada valida

```c
lat_l_active && !crossing_detected
```

### O que faz

- reduz velocidade temporariamente;
- pode aumentar ganho proporcional;
- pode aumentar succao;
- continua seguindo linha;
- dura um tempo curto;
- nao pode ser ativado se houver cruzamento frontal.

### Saidas

```text
CURVE_LEFT -> RUNNING
```

Condicoes:

- tempo de curva acabou;
- linha estabilizou;
- marcador lateral saiu.

```text
CURVE_LEFT -> CROSSING
```

Condicao:

```c
crossing_detected == true
```

```text
CURVE_LEFT -> LINE_LOST
```

Condicao:

```c
line_lost_confirmed == true
```

```text
CURVE_LEFT -> SAFE_STOP
```

Condicoes:

- `STOP_RUN`;
- emergencia;
- falha.

## 5.11 LINE_LOST

### Funcao

Tentar recuperar a linha antes de parar.

### O que faz

- reduz velocidade;
- congela integral;
- usa `last_valid_error`;
- procura para o lado onde a linha foi vista;
- mantem succao conforme configuracao;
- aplica timeout de busca.

### Logica sugerida

```c
if (last_valid_error > 0) {
    procurar_para_um_lado();
} else {
    procurar_para_o_outro_lado();
}
```

### Saidas

```text
LINE_LOST -> RUNNING
```

Condicao:

```c
line_detected && !line_lost
```

```text
LINE_LOST -> SAFE_STOP
```

Condicoes:

- timeout de busca excedido;
- `STOP_RUN`;
- emergencia;
- falha.

## 5.12 FINISH_DETECTED

### Funcao

Finalizar corrida.

### Entrada valida

```c
right_marker_valid && run_time_ms > finish_min_run_time_ms
```

### O que faz

- registra tempo final;
- reduz motores;
- envia evento ao ESP32;
- desliga succao;
- prepara parada segura.

### Saida

```text
FINISH_DETECTED -> SAFE_STOP
```

Condicao:

```text
fim registrado
```

## 5.13 SAFE_STOP

### Funcao

Parar tudo em seguranca.

### O que faz

- PWM motores = `0`;
- TB6612 em brake ou coast;
- succao desligada;
- integral do PID zerada;
- derivativo resetado;
- corrida bloqueada ate clear/reset;
- envia estado ao ESP32.

### Saidas

```text
SAFE_STOP -> IDLE
```

Condicoes:

- ESP32 envia `DISARM`;
- clear/reset seguro;
- falha recuperavel foi limpa.

Opcao futura:

```text
SAFE_STOP -> READY
```

Condicao:

```text
manter calibracao valida depois da parada
```

Para Rev A0, recomendacao:

```text
SAFE_STOP -> IDLE
```

## 5.14 HARDWARE_TEST

### Funcao

Testar hardware isolado em bancada.

### O que faz

- testa motor esquerdo;
- testa motor direito;
- testa ambos os motores;
- testa succao;
- testa sensores;
- testa LEDs futuros;
- sempre com timeout;
- sempre aceita STOP imediato.

### Regras

```text
rodas suspensas nos primeiros testes de motor
succao testada isolada medindo corrente
STOP sempre visivel no dashboard
```

### Saidas

```text
HARDWARE_TEST -> IDLE
```

Condicao:

```text
teste terminou normalmente
```

```text
HARDWARE_TEST -> SAFE_STOP
```

Condicoes:

- timeout;
- `STOP_RUN`;
- falha.

## 5.15 ERROR

### Funcao

Estado de falha critica.

### O que faz

- motores desligados;
- succao desligada;
- TB6612 desabilitado;
- envia erro ao ESP32;
- bloqueia `START_RUN`;
- aguarda reset ou clear controlado.

### Entradas

Qualquer estado pode ir para `ERROR`.

Condicoes:

- configuracao invalida sem fallback;
- ADC falhando;
- sensor critico invalido;
- watchdog interno;
- bateria critica;
- falha de hardware nao recuperavel.

### Saida

```text
ERROR -> IDLE
```

Condicao:

```text
reset ou clear, apenas se a falha desapareceu
```

## 6. Resumo Das Setas

| Transicao | Condicao |
|---|---|
| `BOOT -> SELF_TEST` | Inicializacao terminou |
| `BOOT -> ERROR` | Falha critica na inicializacao |
| `SELF_TEST -> IDLE` | Sistema basico OK |
| `SELF_TEST -> ERROR` | Configuracao/hardware invalido |
| `IDLE -> CALIBRATION` | `CALIBRATION_START` |
| `IDLE -> READY` | Calibracao valida existente |
| `IDLE -> HARDWARE_TEST` | `HARDWARE_TEST` |
| `CALIBRATION -> READY` | Calibracao concluida e valida |
| `CALIBRATION -> IDLE` | Calibracao cancelada |
| `CALIBRATION -> ERROR` | Sensor/ADC falhou |
| `READY -> ARMED` | `ARM` |
| `READY -> CALIBRATION` | Recalibrar |
| `READY -> IDLE` | Reset/cancelamento |
| `ARMED -> FAN_SPINUP` | `START_RUN` ou `LAT_R && !crossing` |
| `ARMED -> READY` | `DISARM` |
| `ARMED -> SAFE_STOP` | Stop ou falha |
| `FAN_SPINUP -> RUNNING` | Delay da succao terminou |
| `FAN_SPINUP -> SAFE_STOP` | Stop/falha |
| `RUNNING -> CROSSING` | Cruzamento frontal |
| `CROSSING -> RUNNING` | Cruzamento acabou |
| `RUNNING -> CURVE_LEFT` | `LAT_L && !crossing` |
| `CURVE_LEFT -> RUNNING` | Tempo/evento de curva acabou |
| `CURVE_LEFT -> CROSSING` | Cruzamento apareceu |
| `RUNNING -> LINE_LOST` | Linha perdida confirmada |
| `LINE_LOST -> RUNNING` | Linha reencontrada |
| `LINE_LOST -> SAFE_STOP` | Timeout de busca |
| `RUNNING -> FINISH_DETECTED` | `LAT_R && !crossing && tempo minimo` |
| `FINISH_DETECTED -> SAFE_STOP` | Fim registrado |
| `SAFE_STOP -> IDLE` | Clear/reset/disarm |
| `qualquer estado -> SAFE_STOP` | Stop/emergencia/falha recuperavel |
| `qualquer estado -> ERROR` | Falha critica |

## 7. Variaveis Principais

### Sensores

```c
front_raw[8]
front_norm[8]
lat_l_raw
lat_l_norm
lat_r_raw
lat_r_norm
front_sum
active_count
strong_count
span
position
error
last_valid_error
```

### Eventos

```c
crossing_detected
line_lost
line_lost_confirmed
lat_l_active
lat_r_active
left_curve_valid
right_marker_valid
```

### Controle

```c
kp
ki
kd
integral_limit
derivative_filter
base_speed
pwm_min_left
pwm_min_right
pwm_max_left
pwm_max_right
fan_pwm_start
fan_pwm_run
fan_pwm_max
```

## 8. Pseudocodigo Do RUNNING

```c
if (stop_requested || emergency_fault) {
    state = ST_SAFE_STOP;
}
else if (critical_fault) {
    state = ST_ERROR;
}
else if (crossing_detected) {
    state = ST_CROSSING;
}
else if (line_lost_confirmed) {
    state = ST_LINE_LOST;
}
else if (right_marker_valid && run_time_ms > finish_min_run_time_ms) {
    state = ST_FINISH_DETECTED;
}
else if (left_curve_valid) {
    state = ST_CURVE_LEFT;
}
else {
    run_pid();
    update_motors();
}
```

## 9. Relacao Com ESP32

O ESP32 pode enviar:

- `SET_PID`;
- `SET_MOTOR_CONFIG`;
- `SET_FAN_CONFIG`;
- `CALIBRATION_START`;
- `CALIBRATION_STOP`;
- `ARM`;
- `DISARM`;
- `START_RUN`;
- `STOP_RUN`;
- `HARDWARE_TEST`;
- `PING`.

O STM32 responde:

- `ACK`;
- `NACK`;
- `PONG`;
- `TELEMETRY_BASIC`;
- `SENSOR_VALUES`;
- `ERROR_STATUS`.

Regra:

```text
ESP32 configura, monitora e registra.
STM32 decide e executa em tempo real.
```

## 10. Pendencias Rev A0

- Definir se `SAFE_STOP -> READY` sera permitido mantendo calibracao.
- Definir botao fisico de STOP, se existir.
- Definir timeout exato de `LINE_LOST`.
- Definir duracao e ganhos especiais de `CURVE_LEFT`.
- Definir se modo competicao ignora perda de ESP32 durante corrida.
- Validar sinais dos sensores reais na bancada.
- Validar sentido dos motores e sinal da correcao PID.

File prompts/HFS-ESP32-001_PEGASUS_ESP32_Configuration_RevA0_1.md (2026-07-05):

# HFS-ESP32-001 — PEGASUS ESP32-S3 Configuration Specification

Projeto: **PEGASUS Line Follower Robot**  
Placa oficial futura: **HDB-001 Brain Board**  
Módulo oficial futuro: **Seeed XIAO ESP32-S3 / XIAO ESP32-S3 Plus**  
Módulo de bancada inicial: **ESP32-S3 Zero**  
Documento: **HFS-ESP32-001**  
Revisão: **A0.1 — atualizada com etapa de protoboard**  
Responsável: **Wesley Mateus Basso / Hander**

---

## 1. Objetivo deste documento

Este documento define a arquitetura do firmware do ESP32-S3 no projeto PEGASUS.

A nova decisão da Rev A0.1 é:

> Antes de usar o Seeed XIAO ESP32-S3 na placa oficial, será usado um **ESP32-S3 Zero** em protoboard para validar comunicação, dashboard, protocolo UART e integração com STM32 Black Pill.

Isso reduz risco de queimar o módulo Seeed XIAO e permite testar a lógica do sistema com baixo custo.

---

## 2. Papel do ESP32-S3 no PEGASUS

O ESP32-S3 atua como:

```text
copiloto
central de telemetria
interface web
configurador de parâmetros
logger
engenheiro de pista
```

Ele **não controla o robô em tempo real**.

```text
STM32F411 = piloto em tempo real
ESP32-S3  = interface, telemetria, logs, configuração e análise
```

---

## 3. Divisão entre STM32 e ESP32

### 3.1 STM32F411 — controle crítico

O STM32 é responsável por tudo que precisa ser determinístico:

- leitura ADC dos sensores analógicos;
- normalização dos sensores;
- detecção de linha;
- detecção de cruzamento;
- detecção dos sensores laterais;
- máquina de estados principal;
- PID;
- PWM real dos motores;
- PWM real da sucção;
- segurança crítica;
- watchdog;
- parada de emergência.

### 3.2 ESP32-S3 — interface e inteligência auxiliar

O ESP32 é responsável por:

- criar interface web local;
- receber telemetria do STM32 via UART;
- enviar comandos ao STM32;
- iniciar/parar calibração;
- exibir sensores frontais e laterais;
- alterar parâmetros PID;
- alterar PWM base, máximo e mínimo dos motores;
- alterar PWM da sucção;
- iniciar/parar o robô;
- salvar perfis de configuração;
- registrar logs de testes/corridas;
- analisar comportamento do robô;
- sugerir ajustes de PID, sensores, velocidade e sucção;
- gerenciar Wi-Fi/BLE;
- futuramente permitir OTA.

### 3.3 Regra fundamental

```text
ESP32 nunca deve gerar diretamente o PWM dos motores.
ESP32 nunca deve rodar o PID principal.
ESP32 nunca deve decidir sozinho segurança crítica.
```

O ESP32 pode sugerir, configurar e enviar comandos.  
O STM32 executa o controle real.

---

## 4. Estratégia de hardware por fases

### 4.1 Fase 0 — bancada/protoboard

Objetivo: validar firmware e comunicação antes da placa.

Usar:

- STM32 Black Pill F411;
- ESP32-S3 Zero;
- protoboard/jumpers;
- alimentação por USB separada inicialmente;
- GND comum obrigatório.

Arquitetura:

```text
PC / celular
    ↓ Wi-Fi
ESP32-S3 Zero
    ↓ UART
STM32 Black Pill
    ↓
telemetria fake primeiro
sensores reais depois
motores depois
```

Ligação mínima:

```text
STM32 PA9  TX  →  RX do ESP32-S3 Zero
STM32 PA10 RX  ←  TX do ESP32-S3 Zero
GND             ↔  GND
```

Recomendação inicial:

```text
ESP32-S3 Zero alimentado pelo próprio USB.
Black Pill alimentada pelo próprio USB/ST-Link.
GND comum entre os dois.
```

Não alimentar um módulo pelo outro no primeiro teste.

---

### 4.2 Fase 1 — carrinho de teste

Objetivo: validar comunicação + sensores + motores.

Usar:

- STM32 Black Pill;
- ESP32-S3 Zero;
- TB6612;
- sensores analógicos;
- motores N20;
- bateria 2S;
- buck 5V.

O ESP32-S3 Zero continua sendo usado para proteger o XIAO.

---

### 4.3 Fase 2 — Brain Board oficial

Objetivo: migrar o mesmo firmware para o Seeed XIAO ESP32-S3.

Usar:

- HDB-001 Brain Board;
- Seeed XIAO ESP32-S3 ou XIAO ESP32-S3 Plus;
- HDB-100 Chassis Board;
- HDB-101 Sensor Board.

O firmware deve mudar apenas o perfil de pinos.

---

## 5. Suporte a múltiplas placas ESP32

O firmware deve suportar pelo menos dois alvos:

```text
BOARD_ESP32_S3_ZERO
BOARD_XIAO_ESP32_S3
```

Criar arquivo:

```text
firmware/esp32/board_pins.h
```

Exemplo:

```cpp
#pragma once

// Selecione apenas uma placa por vez.
// #define BOARD_ESP32_S3_ZERO
// #define BOARD_XIAO_ESP32_S3

#if defined(BOARD_ESP32_S3_ZERO)

    #define BOARD_NAME "ESP32-S3 Zero Dev Prototype"

    // ATENÇÃO:
    // Preencher estes pinos conforme o modelo exato do ESP32-S3 Zero usado.
    // Não assumir pinagem sem conferir serigrafia/datasheet.
    #define STM32_UART_NUM      1
    #define STM32_UART_TX_PIN   -1  // TODO: definir
    #define STM32_UART_RX_PIN   -1  // TODO: definir

    #define STATUS_LED_PIN      -1  // TODO: definir se existir LED onboard
    #define BOOT_BUTTON_PIN     -1  // opcional

#elif defined(BOARD_XIAO_ESP32_S3)

    #define BOARD_NAME "Seeed XIAO ESP32-S3 Brain Board"

    // ATENÇÃO:
    // Preencher conforme o modelo exato: XIAO ESP32-S3 ou XIAO ESP32-S3 Plus.
    #define STM32_UART_NUM      1
    #define STM32_UART_TX_PIN   -1  // TODO: definir após pinout da HDB-001
    #define STM32_UART_RX_PIN   -1  // TODO: definir após pinout da HDB-001

    #define STATUS_LED_PIN      -1
    #define BOOT_BUTTON_PIN     -1

#else
    #error "Selecione BOARD_ESP32_S3_ZERO ou BOARD_XIAO_ESP32_S3"
#endif
```

Regra para o Codex:

> Não fixar pinos reais sem confirmação do modelo físico.  
> Deixar `TODO` quando a pinagem depender do módulo exato.

---

## 6. Uso dos dois cores do ESP32-S3

Usar FreeRTOS com tarefas fixadas em cores.

### Core 0 — Comunicação e infraestrutura

Responsável por:

- UART com STM32;
- parser de pacotes;
- envio de comandos;
- recepção de telemetria;
- watchdog de comunicação;
- gerenciamento Wi-Fi básico;
- OTA futura.

### Core 1 — Interface, logs e inteligência

Responsável por:

- web dashboard;
- API HTTP/WebSocket;
- logs;
- perfis;
- NVS/Flash;
- análise da corrida;
- sugestões automáticas;
- diagnóstico.

---

## 7. Tarefas FreeRTOS

### 7.1 Core 0

#### `uart_rx_task`

```text
Core: 0
Prioridade: Alta
Função: receber telemetria do STM32 sem perder pacotes.
```

Responsabilidades:

- ler bytes da UART;
- montar frames;
- validar CRC;
- atualizar estrutura de telemetria;
- enviar dados para `telemetry_queue`.

#### `uart_tx_task`

```text
Core: 0
Prioridade: Alta
Função: enviar comandos ao STM32.
```

Responsabilidades:

- receber comandos da `command_queue`;
- empacotar frames;
- calcular CRC;
- enviar para STM32;
- aguardar ACK/NACK quando necessário.

#### `stm32_watchdog_task`

```text
Core: 0
Prioridade: Média
Período: 100 ms
```

Responsabilidades:

- verificar tempo desde último pacote recebido;
- marcar STM32 como online/offline;
- notificar dashboard;
- bloquear comandos perigosos se STM32 estiver offline.

#### `wifi_manager_task`

```text
Core: 0
Prioridade: Média
```

Responsabilidades:

- criar Access Point;
- opcionalmente conectar a rede externa;
- manter status de rede;
- reiniciar Wi-Fi em caso de falha.

---

### 7.2 Core 1

#### `web_server_task`

```text
Core: 1
Prioridade: Média
```

Responsabilidades:

- servir página HTML;
- receber comandos do usuário;
- exibir telemetria;
- atualizar gráficos;
- expor API REST/WebSocket.

#### `logger_task`

```text
Core: 1
Prioridade: Baixa/Média
```

Responsabilidades:

- salvar telemetria em buffer;
- exportar CSV;
- registrar eventos;
- evitar escrita em Flash em frequência excessiva.

#### `analyzer_task`

```text
Core: 1
Prioridade: Baixa
```

Responsabilidades:

- calcular erro médio;
- calcular erro máximo;
- contar perdas de linha;
- contar saturação dos motores;
- detectar oscilação;
- detectar velocidade excessiva;
- sugerir ajustes.

#### `profile_manager_task`

```text
Core: 1
Prioridade: Baixa
```

Responsabilidades:

- salvar PID;
- salvar thresholds;
- salvar limites de PWM;
- salvar perfis de pista;
- carregar perfil ativo;
- resetar perfil padrão.

---

## 8. Comunicação interna no ESP32

Usar filas FreeRTOS.

Telemetria:

```text
STM32 UART
   ↓
uart_rx_task
   ↓
telemetry_queue
   ↓
web_server_task
logger_task
analyzer_task
```

Comandos:

```text
Web Dashboard
   ↓
command_queue
   ↓
uart_tx_task
   ↓
STM32
```

Filas recomendadas:

```cpp
QueueHandle_t telemetry_queue;
QueueHandle_t command_queue;
QueueHandle_t event_queue;
QueueHandle_t log_queue;
```

---

## 9. UART ESP32 ↔ STM32

Configuração inicial:

```text
Baudrate: 115200
Formato: 8N1
Flow control: nenhum
```

Configuração futura:

```text
Baudrate: 921600
```

Só subir baudrate depois da comunicação estar estável.

---

## 10. Protocolo UART

Frame binário:

```text
SOF | TYPE | LEN | PAYLOAD | CRC8
```

| Campo | Tamanho | Descrição |
|---|---|---|
| SOF | 1 byte | Sempre `0xA5` |
| TYPE | 1 byte | Tipo da mensagem |
| LEN | 1 byte | Tamanho do payload |
| PAYLOAD | N bytes | Dados |
| CRC8 | 1 byte | Validação |

### Tipos de mensagem

| Código | Nome | Direção | Função |
|---:|---|---|---|
| `0x01` | TELEMETRY_BASIC | STM32 → ESP32 | Estado geral |
| `0x02` | SENSOR_VALUES | STM32 → ESP32 | Sensores analógicos |
| `0x03` | SET_PID | ESP32 → STM32 | Alterar PID |
| `0x04` | SET_MOTOR_CONFIG | ESP32 → STM32 | PWM motores |
| `0x05` | SET_FAN_CONFIG | ESP32 → STM32 | PWM sucção |
| `0x06` | CALIBRATION_START | ESP32 → STM32 | Iniciar calibração |
| `0x07` | CALIBRATION_STOP | ESP32 → STM32 | Finalizar calibração |
| `0x08` | START_RUN | ESP32 → STM32 | Iniciar corrida |
| `0x09` | STOP_RUN | ESP32 → STM32 | Parar robô |
| `0x0A` | ARM | ESP32 → STM32 | Armar robô |
| `0x0B` | DISARM | ESP32 → STM32 | Desarmar robô |
| `0x0C` | HARDWARE_TEST | ESP32 → STM32 | Teste de hardware |
| `0x0D` | ERROR_STATUS | STM32 → ESP32 | Erros |
| `0x0E` | ACK | Bidirecional | Confirmação |
| `0x0F` | NACK | Bidirecional | Falha |

---

## 11. Estados do robô exibidos pelo ESP32

O ESP32 deve refletir a máquina de estados do STM32.

```cpp
typedef enum {
    ROBOT_BOOT = 0,
    ROBOT_IDLE,
    ROBOT_CALIBRATION,
    ROBOT_READY,
    ROBOT_ARMED,
    ROBOT_RUNNING,
    ROBOT_CROSSING,
    ROBOT_CURVE_LEFT,
    ROBOT_FINISH_DETECTED,
    ROBOT_LINE_LOST,
    ROBOT_SAFE_STOP,
    ROBOT_ERROR
} robot_state_t;
```

Estados perigosos que devem aparecer em destaque:

- `ROBOT_LINE_LOST`;
- `ROBOT_SAFE_STOP`;
- `ROBOT_ERROR`;
- STM32 offline;
- bateria baixa.

---

## 12. Dashboard Web

O ESP32 deve criar um Access Point Wi-Fi.

```text
SSID padrão: PEGASUS_SETUP
Senha padrão: pegasus123
Endereço local: 192.168.4.1
```

---

## 13. Seções do Dashboard

### 13.1 Status

Mostrar:

- estado do robô;
- STM32 online/offline;
- bateria;
- linha detectada;
- cruzamento;
- sensor lateral esquerdo;
- sensor lateral direito;
- PWM motor esquerdo;
- PWM motor direito;
- PWM sucção;
- tempo de corrida.

### 13.2 Sensores

Mostrar:

```text
A0 A1 A2 A3 A4 A5 A6 A7
LAT_L
LAT_R
```

Para cada sensor mostrar:

- valor cru;
- valor normalizado;
- threshold;
- estado ativo/inativo.

Exibir gráfico em barras.

### 13.3 Calibração

Botões:

- iniciar calibração;
- finalizar calibração;
- cancelar calibração;
- ver qualidade da calibração;
- salvar calibração;
- resetar calibração.

Mostrar:

- mínimo de cada sensor;
- máximo de cada sensor;
- range;
- threshold calculado;
- ruído estimado.

### 13.4 PID

Parâmetros editáveis:

```text
Kp
Ki
Kd
integral_limit
derivative_filter
```

### 13.5 Motores

Parâmetros editáveis:

```text
base_speed
pwm_min_left
pwm_min_right
pwm_max_left
pwm_max_right
accel_limit
brake_limit
left_motor_inverted
right_motor_inverted
```

Teste manual:

```text
Motor L PWM: -100% a +100%
Motor R PWM: -100% a +100%
Tempo máximo de teste: 3 segundos
Botão STOP sempre visível
```

### 13.6 Sucção

Parâmetros editáveis:

```text
fan_pwm_start
fan_pwm_run
fan_pwm_max
fan_start_delay_ms
fan_mode
```

Modos:

```text
OFF
PWM_DC_MOSFET
ESC_SERVO
```

### 13.7 Eventos e Máquina de Estados

Mostrar eventos detectados:

- CROSSING;
- CURVE_LEFT;
- RIGHT_MARKER;
- FINISH;
- LINE_LOST.

Regra especial:

```text
LAT_R só conta como início/parada se os sensores frontais NÃO indicarem cruzamento.
```

### 13.8 Perfis

Perfis sugeridos:

```text
SAFE
FAST
CURVES
TEST
CUSTOM_1
CUSTOM_2
```

Cada perfil salva:

- PID;
- thresholds;
- PWM motores;
- PWM sucção;
- configurações de cruzamento;
- configurações de linha perdida.

### 13.9 Logs

Mostrar:

- última corrida;
- duração;
- erro médio;
- erro máximo;
- número de cruzamentos;
- número de perdas de linha;
- PWM médio;
- bateria inicial/final.

Exportar como CSV.

### 13.10 Análise inteligente

Botão:

```text
Analisar última corrida
```

Saída esperada:

```text
Diagnóstico:
- Robô oscilou em reta.
- PWM saturou em curvas.
- Linha foi perdida 2 vezes.
- Bateria caiu abaixo do ideal.

Sugestões:
- Reduzir Kp em 10%.
- Aumentar Kd em 15%.
- Reduzir base_speed em 5%.
- Aumentar fan_pwm_run em 10%.
```

As sugestões devem ser opcionais.

---

## 14. Configurações salvas em NVS

Criar estrutura de configuração:

```cpp
typedef struct {
    float kp;
    float ki;
    float kd;
    float integral_limit;
    float derivative_filter;

    uint16_t sensor_threshold[8];
    uint16_t sensor_strong_threshold[8];
    uint16_t lat_l_threshold;
    uint16_t lat_r_threshold;

    uint16_t crossing_sum_threshold;
    uint8_t crossing_min_count;
    uint8_t crossing_min_span;
    uint16_t lost_line_sum_threshold;

    int16_t base_speed;
    int16_t pwm_min_left;
    int16_t pwm_min_right;
    int16_t pwm_max_left;
    int16_t pwm_max_right;
    int16_t accel_limit;
    int16_t brake_limit;

    bool left_motor_inverted;
    bool right_motor_inverted;

    uint16_t fan_pwm_start;
    uint16_t fan_pwm_run;
    uint16_t fan_pwm_max;
    uint16_t fan_start_delay_ms;
    uint8_t fan_mode;

    uint16_t finish_min_run_time_ms;
    uint16_t line_lost_timeout_ms;
    uint16_t crossing_debounce_ms;
    uint16_t lateral_debounce_ms;

    uint32_t config_version;
    uint32_t checksum;
} pegasus_config_t;
```

---

## 15. AutoCalibração dos sensores

O ESP32 deve solicitar ao STM32:

```text
CALIBRATION_START
```

O STM32 mede:

- mínimo;
- máximo;
- ruído;
- range;
- estabilidade.

Depois envia resultados ao ESP32.

O ESP32 calcula ou recebe:

- threshold individual;
- strong threshold individual;
- thresholds laterais;
- qualidade da calibração.

Regra de qualidade:

```text
range = max - min
```

Se:

```text
range < SENSOR_MIN_RANGE
```

Mostrar:

```text
Sensor S3 com contraste baixo. Verifique altura, alinhamento ou iluminação.
```

---

## 16. Inteligência de ajuste

O ESP32 pode sugerir ajustes, mas não aplicar automaticamente durante corrida oficial.

### Modo treino

Pode sugerir e aplicar com confirmação.

### Modo corrida

Parâmetros congelados.

Diagnósticos simples:

- oscilação em reta → reduzir Kp ou aumentar Kd;
- robô atrasado nas curvas → aumentar Kp, reduzir base_speed ou aumentar fan;
- perda de linha → reduzir velocidade, melhorar calibração ou aumentar sucção;
- motor desequilibrado → ajustar pwm_max_left/right ou compensação.

---

## 17. Estrutura de pastas esperada

```text
firmware/esp32/
├── main.cpp
├── app_config.h
├── board_pins.h
├── communication/
│   ├── uart_protocol.cpp
│   ├── uart_protocol.h
│   ├── packet_parser.cpp
│   └── packet_parser.h
├── web/
│   ├── web_server.cpp
│   ├── web_server.h
│   ├── api_routes.cpp
│   ├── api_routes.h
│   └── web_ui.h
├── telemetry/
│   ├── telemetry_model.cpp
│   ├── telemetry_model.h
│   ├── logger.cpp
│   └── logger.h
├── config/
│   ├── config_manager.cpp
│   ├── config_manager.h
│   ├── profiles.cpp
│   └── profiles.h
├── analysis/
│   ├── run_analyzer.cpp
│   └── run_analyzer.h
├── safety/
│   ├── stm32_watchdog.cpp
│   └── stm32_watchdog.h
└── ota/
    ├── ota_update.cpp
    └── ota_update.h
```

---

## 18. Requisitos mínimos da Rev A0

A primeira versão do firmware ESP32 deve implementar:

- suporte ao perfil `BOARD_ESP32_S3_ZERO`;
- suporte futuro ao perfil `BOARD_XIAO_ESP32_S3`;
- Wi-Fi Access Point;
- Web dashboard simples;
- UART com STM32;
- exibir estado do robô;
- exibir sensores;
- alterar PID;
- alterar PWM dos motores;
- alterar PWM da sucção;
- iniciar/parar calibração;
- armar;
- start;
- stop;
- salvar configuração em NVS.

---

## 19. Plano de testes na protoboard

### Teste 1 — UART básica

Objetivo:

```text
ESP32-S3 Zero envia PING.
STM32 responde PONG.
```

Critério de sucesso:

```text
ACK recebido por 1000 ciclos sem erro.
```

### Teste 2 — telemetria fake

Objetivo:

```text
STM32 envia sensores falsos A0-A7.
ESP32 mostra no dashboard.
```

### Teste 3 — comandos

Objetivo:

```text
Dashboard envia ARM, START, STOP e calibração.
STM32 responde ACK.
```

### Teste 4 — sensores reais

Objetivo:

```text
STM32 lê sensores analógicos reais.
ESP32 exibe gráfico de barras.
```

### Teste 5 — motores

Objetivo:

```text
ESP32 envia teste de motor.
STM32 aciona TB6612 com timeout.
```

Regra:

```text
Sempre testar com rodas suspensas primeiro.
```

### Teste 6 — sucção

Objetivo:

```text
ESP32 envia teste de fan/sucção.
STM32 aciona FAN_PWM com timeout.
```

---

## 20. Instruções para o Codex

Ao gerar código:

1. Não misturar controle crítico no ESP32.
2. Fixar tarefas UART no Core 0.
3. Fixar dashboard/análise no Core 1.
4. Usar filas FreeRTOS.
5. Criar código modular.
6. Criar structs claras.
7. Criar comentários explicando a separação STM32/ESP32.
8. Não aplicar sugestões automáticas durante corrida sem confirmação.
9. Priorizar Rev A0 funcional antes de recursos avançados.
10. Não depender de Wi-Fi para o robô correr.
11. Suportar primeiro `BOARD_ESP32_S3_ZERO`.
12. Deixar preparado para migrar para `BOARD_XIAO_ESP32_S3`.
13. Não inventar pinagem real sem confirmação.

---

## 21. Prompt curto para Codex

```text
Implemente o firmware ESP32-S3 do projeto PEGASUS conforme o documento HFS-ESP32-001 Rev A0.1.

A primeira fase usará ESP32-S3 Zero em protoboard para validar comunicação com STM32 Black Pill. Depois o firmware será migrado para Seeed XIAO ESP32-S3 na HDB-001 Brain Board.

Use FreeRTOS com duas divisões principais:
- Core 0: UART com STM32, parser de pacotes, command queue, watchdog e Wi-Fi manager.
- Core 1: web dashboard, logs, perfis, NVS e análise inteligente.

Não implemente PID nem controle direto de motores no ESP32. O ESP32 deve apenas enviar comandos e parâmetros para o STM32.

Crie a estrutura de pastas em firmware/esp32/ conforme especificado.

Implemente inicialmente:
- suporte ao perfil BOARD_ESP32_S3_ZERO;
- arquivo board_pins.h com TODOs claros para pinos;
- Access Point PEGASUS_SETUP;
- dashboard web simples;
- UART protocol frame SOF/TYPE/LEN/PAYLOAD/CRC8;
- exibição de sensores;
- alteração de PID;
- alteração de PWM dos motores;
- alteração de PWM da sucção;
- start/stop/calibração/arm;
- salvar configuração em NVS;
- watchdog de comunicação com STM32.

Deixe preparado para BOARD_XIAO_ESP32_S3, mas não assuma pinos reais sem confirmação.

Documente pendências para Rev A1 e não invente lógica crítica fora da especificação.
```

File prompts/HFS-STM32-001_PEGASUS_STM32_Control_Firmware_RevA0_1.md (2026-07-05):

# HFS-STM32-001 — PEGASUS STM32F411 Control Firmware Specification

Projeto: **PEGASUS Line Follower Robot**  
Placa principal: **HDB-001 Brain Board**  
Placa inferior: **HDB-100 Chassis / Power Board**  
Placa de sensores: **HDB-101 Sensor Board**  
MCU de controle: **STM32F411CEU6 / Black Pill F411**  
Documento: **HFS-STM32-001**  
Revisão: **A0.1**  
Responsável: **Wesley Mateus Basso / Hander**

---

## 1. Função do STM32 no PEGASUS

O STM32F411 é o **piloto real do robô**.

Ele é responsável por tudo que precisa de tempo real, previsibilidade e segurança.

```text
STM32F411 = piloto em tempo real
ESP32-S3  = interface, telemetria, logs, configuração e análise
```

O STM32 deve continuar funcionando mesmo se o ESP32 travar, reiniciar ou perder Wi-Fi.

---

## 2. Observação sobre cores do STM32F411

O STM32F411 **não é dual-core**.  
Ele possui um único núcleo:

```text
ARM Cortex-M4F single-core com FPU
```

Portanto, para “usar o máximo” do STM32, o firmware deve explorar:

- timers de hardware;
- PWM por timer;
- ADC em scan mode;
- DMA para leitura dos sensores;
- interrupção periódica de controle;
- UART com interrupção ou DMA;
- watchdog;
- FPU para cálculo PID;
- código enxuto e determinístico.

O paralelismo vem dos **periféricos de hardware**, não de múltiplos cores.

---

## 3. Responsabilidades do STM32

O STM32 deve controlar:

- sensores frontais analógicos;
- sensores laterais analógicos;
- calibração dos sensores;
- normalização dos sensores;
- detecção de linha;
- detecção de cruzamento;
- detecção do sensor lateral esquerdo de curva;
- detecção do sensor lateral direito de início/parada;
- máquina de estados principal;
- controle PID/PD;
- PWM dos motores via TB6612FNG;
- PWM da sucção;
- leitura de bateria;
- segurança crítica;
- comunicação UART com ESP32;
- envio de telemetria;
- resposta a comandos;
- testes de hardware.

---

## 4. Sensores

### 4.1 Sensores frontais

O robô usa 8 sensores frontais analógicos:

```text
S0 S1 S2 S3 S4 S5 S6 S7
```

Funções:

- seguir a linha;
- calcular posição da linha;
- calcular erro do PID;
- detectar cruzamento;
- detectar linha perdida.

### 4.2 Sensor lateral esquerdo

```text
LAT_L
```

Função:

- detectar marca lateral de curva;
- acionar modo especial de curva esquerda.

### 4.3 Sensor lateral direito

```text
LAT_R
```

Função:

- detectar início;
- detectar parada/fim.

Regra especial:

```text
LAT_R só conta como início/parada se os sensores frontais NÃO indicarem cruzamento.
```

Se `LAT_R` estiver ativo, mas os sensores frontais também indicarem padrão largo/equivalente, o evento deve ser tratado como:

```text
CROSSING
```

e não como início/fim.

---

## 5. Fluxo de leitura dos sensores

A leitura deve seguir este pipeline:

```text
ADC cru
 ↓
filtro
 ↓
normalização pela calibração
 ↓
extração de características
 ↓
eventos lógicos
 ↓
máquina de estados
 ↓
PID / motores
```

---

## 6. Leitura ADC

### 6.1 Canais ADC mínimos

```text
S0 a S7   = 8 canais analógicos frontais
LAT_L     = 1 canal analógico lateral esquerdo
LAT_R     = 1 canal analógico lateral direito
VBAT_ADC  = opcional, se houver canal disponível
```

Total mínimo:

```text
10 canais analógicos
```

Total com bateria:

```text
11 canais analógicos
```

### 6.2 Estratégia recomendada

Usar:

```text
ADC1 em scan mode
DMA circular
buffer de amostras
```

O controle não deve ficar bloqueado esperando ADC.

### 6.3 Frequências sugeridas

```text
ADC scan: 2 kHz a 10 kHz agregado
Controle: 500 Hz a 1 kHz
Telemetria: 20 Hz a 50 Hz
PWM motores: 20 kHz a 25 kHz
PWM fan DC: 20 kHz a 25 kHz
PWM ESC/servo: 50 Hz, se usar ESC
```

---

## 7. Calibração dos sensores

Durante a calibração, o STM32 deve registrar para cada sensor:

```c
sensor_min[i]
sensor_max[i]
sensor_noise[i]
```

Depois calcular:

```c
sensor_range[i] = sensor_max[i] - sensor_min[i];
```

Um sensor com range baixo deve ser marcado como suspeito.

```c
if (sensor_range[i] < SENSOR_MIN_RANGE) {
    sensor_fault[i] = true;
}
```

---

## 8. Normalização

Após calibração, cada sensor deve ser normalizado para uma escala comum:

```text
0    = sem linha
1000 = linha forte
```

Exemplo:

```c
norm[i] = (raw[i] - min[i]) * 1000 / (max[i] - min[i]);
```

Com saturação:

```c
if (norm[i] < 0) norm[i] = 0;
if (norm[i] > 1000) norm[i] = 1000;
```

Se a linha for branca em fundo preto, aplicar inversão:

```c
norm[i] = 1000 - norm[i];
```

---

## 9. Filtro dos sensores

Usar filtro IIR leve:

```c
filtered[i] = (filtered[i] * 7 + raw[i] * 3) / 10;
```

Filtro muito forte deixa o robô lento.  
Filtro muito fraco deixa o robô nervoso.

Parâmetro configurável pelo ESP32:

```text
sensor_filter_alpha
```

---

## 10. Cálculo da posição da linha

Usar média ponderada dos sensores frontais.

Pesos sugeridos:

```text
S0    S1    S2    S3    S4    S5    S6    S7
-3500 -2500 -1500 -500  +500 +1500 +2500 +3500
```

Fórmula:

```c
position = sum(norm[i] * weight[i]) / sum(norm[i]);
```

Erro:

```c
error = target_position - position;
```

Normalmente:

```c
target_position = 0;
```

Interpretação:

```text
error < 0  = linha para um lado
error > 0  = linha para o outro lado
```

A direção exata deve ser conferida no teste dos motores.

---

## 11. Extração de características dos sensores frontais

A cada ciclo de controle, calcular:

```c
front_sum
active_count
strong_count
first_active
last_active
span
position
error
```

### 11.1 Sensor ativo

```c
active[i] = norm[i] > sensor_threshold[i];
```

### 11.2 Sensor fortemente ativo

```c
strong_active[i] = norm[i] > sensor_strong_threshold[i];
```

### 11.3 Soma frontal

```c
front_sum = norm[0] + norm[1] + ... + norm[7];
```

### 11.4 Largura do padrão

```c
span = last_active - first_active + 1;
```

---

## 12. Detecção de cruzamento

Cruzamento deve ser detectado pelos sensores frontais, não pelos laterais.

Critérios recomendados:

```c
crossing_detected =
    strong_count >= crossing_min_count &&
    span >= crossing_min_span &&
    front_sum >= crossing_sum_threshold;
```

Valores iniciais sugeridos:

```text
crossing_min_count = 5
crossing_min_span = 5
crossing_sum_threshold = 3500
```

Esses valores devem ser ajustáveis pelo ESP32.

### 12.1 Debounce de cruzamento

O cruzamento só deve ser confirmado após persistir por alguns milissegundos.

```text
crossing_debounce_ms = 20 a 50 ms
```

### 12.2 Regra de prioridade

Se cruzamento for detectado:

```text
ignorar LAT_L
ignorar LAT_R
```

---

## 13. Detecção dos sensores laterais

### 13.1 Lateral esquerdo

```c
lat_l_active = lat_l_norm > lat_l_threshold;
```

Evento válido:

```c
left_curve_valid = lat_l_active && !crossing_detected;
```

### 13.2 Lateral direito

```c
lat_r_active = lat_r_norm > lat_r_threshold;
```

Evento válido:

```c
right_marker_valid = lat_r_active && !crossing_detected;
```

Regra principal:

```text
Se houver detecção equivalente na frente, é cruzamento.
O sensor lateral direito não conta como início ou fim.
```

---

## 14. Detecção de linha perdida

Linha perdida:

```c
line_lost = front_sum < lost_line_sum_threshold;
```

Não parar instantaneamente. Usar temporizador:

```c
if (line_lost) {
    line_lost_timer += dt;
} else {
    line_lost_timer = 0;
}
```

Confirmar perda:

```c
line_lost_confirmed = line_lost_timer > line_lost_timeout_ms;
```

Valor inicial sugerido:

```text
line_lost_timeout_ms = 80 ms
```

---

## 15. Máquina de estados principal

Estados:

```c
typedef enum {
    ST_BOOT = 0,
    ST_SELF_TEST,
    ST_IDLE,
    ST_CALIBRATION,
    ST_READY,
    ST_ARMED,
    ST_FAN_SPINUP,
    ST_RUNNING,
    ST_CROSSING,
    ST_CURVE_LEFT,
    ST_LINE_LOST,
    ST_FINISH_DETECTED,
    ST_SAFE_STOP,
    ST_HARDWARE_TEST,
    ST_ERROR
} robot_state_t;
```

---

## 16. Diagrama geral

```text
BOOT
 ↓
SELF_TEST
 ↓
IDLE
 ↓
CALIBRATION
 ↓
READY
 ↓
ARMED
 ↓
FAN_SPINUP
 ↓
RUNNING
 ├── CROSSING
 ├── CURVE_LEFT
 ├── LINE_LOST
 ├── FINISH_DETECTED
 └── SAFE_STOP
```

---

## 17. Descrição dos estados

### 17.1 ST_BOOT

Ações:

- inicializar clock;
- inicializar GPIO;
- inicializar ADC + DMA;
- inicializar timers;
- inicializar PWM;
- inicializar UART;
- inicializar watchdog;
- carregar configuração;
- motores desligados;
- sucção desligada.

Transição:

```text
ST_BOOT → ST_SELF_TEST
```

---

### 17.2 ST_SELF_TEST

Ações:

- verificar configuração válida;
- verificar ADC ativo;
- verificar comunicação básica;
- verificar calibração salva;
- verificar bateria se VBAT_ADC existir.

Transições:

```text
ST_SELF_TEST → ST_IDLE
ST_SELF_TEST → ST_ERROR se falha crítica
```

---

### 17.3 ST_IDLE

Robô parado.

Ações:

- motores em 0;
- STBY do TB6612 desligado;
- sucção desligada;
- aguardando comando.

Transições:

```text
ST_IDLE → ST_CALIBRATION se comando CALIBRATE
ST_IDLE → ST_READY se calibração válida
ST_IDLE → ST_HARDWARE_TEST se comando de teste
```

---

### 17.4 ST_CALIBRATION

Ações:

- coletar min/max dos sensores;
- calcular range;
- calcular thresholds;
- enviar progresso ao ESP32;
- motores desligados, exceto se houver modo manual específico.

Transições:

```text
ST_CALIBRATION → ST_READY se calibração concluída
ST_CALIBRATION → ST_IDLE se cancelada
ST_CALIBRATION → ST_ERROR se sensor crítico falhar
```

---

### 17.5 ST_READY

Robô calibrado, mas não armado.

Ações:

- motores desligados;
- sucção desligada;
- aceitar ajuste de parâmetros;
- aceitar ARM.

Transições:

```text
ST_READY → ST_ARMED se comando ARM
ST_READY → ST_CALIBRATION se recalibrar
ST_READY → ST_IDLE se reset/cancelar
```

---

### 17.6 ST_ARMED

Robô pronto para largar.

Ações:

- motores ainda em 0;
- TB6612 pode ficar em standby desligado;
- sucção pode ficar desligada ou em pré-armamento;
- aguardar START pelo ESP32 ou marcador lateral direito.

Transições:

```text
ST_ARMED → ST_FAN_SPINUP se START pelo ESP32
ST_ARMED → ST_FAN_SPINUP se LAT_R ativo && !crossing_detected
ST_ARMED → ST_READY se DISARM
ST_ARMED → ST_SAFE_STOP se STOP
```

---

### 17.7 ST_FAN_SPINUP

Estado opcional para subir a sucção antes da largada.

Ações:

- ligar sucção em `fan_pwm_start`;
- aguardar `fan_start_delay_ms`;
- manter motores em 0.

Transições:

```text
ST_FAN_SPINUP → ST_RUNNING após delay
ST_FAN_SPINUP → ST_SAFE_STOP se STOP
```

---

### 17.8 ST_RUNNING

Estado principal da corrida.

Ações:

- ler sensores normalizados;
- calcular posição da linha;
- detectar eventos;
- executar PID/PD;
- atualizar motores;
- manter sucção em `fan_pwm_run`;
- enviar telemetria.

Prioridade de eventos:

```text
1. STOP manual ou emergência
2. Falha crítica
3. Cruzamento frontal
4. Linha perdida
5. Sensor direito de fim/parada
6. Sensor esquerdo de curva
7. Seguimento normal por PID
```

Transições:

```text
ST_RUNNING → ST_SAFE_STOP se STOP/emergência
ST_RUNNING → ST_CROSSING se crossing_detected
ST_RUNNING → ST_LINE_LOST se line_lost_confirmed
ST_RUNNING → ST_FINISH_DETECTED se right_marker_valid && run_time > finish_min_run_time_ms
ST_RUNNING → ST_CURVE_LEFT se left_curve_valid
ST_RUNNING → ST_RUNNING caso normal
```

---
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

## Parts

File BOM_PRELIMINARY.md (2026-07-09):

# BOM Preliminar — PEGASUS Rev A0

## HDB-001

| Item | Qtd | Observação |
|---|----:|---|
| Black Pill STM32F411 | 1 | já possui |
| XIAO ESP32-S3/Plus | 1 | confirmar modelo |
| Mini360 opcional | 1 | DNP se 5V vier do chassi |
| Soquetes 2.54mm | vários | Black Pill/XIAO |
| J1 2x6 board-to-board | 1 | sensores |
| J2 2x6 board-to-board | 1 | comandos |
| SWD 5 pinos | 1 | debug |
| UART 4 pinos | 1 | debug |
| LEDs | 4–5 | status |
| Resistores 1k | 4–5 | LEDs |
| Resistores 47R | 2 | UART |
| Capacitores 100nF | 4–8 | desacoplamento |
| Test points | 8–12 | debug |

## HDB-100

| Item | Qtd | Observação |
|---|----:|---|
| XT30 | 1 | bateria |
| Chave | 1 | confirmar corrente |
| TB6612FNG módulo | 1 | plugável |
| Mini360/buck | 1 | 5V |
| Capacitor 470–1000uF | 1–3 | VBAT |
| Capacitores 100nF | 6–12 | filtragem |
| Conector motor L | 1 | 2 pinos |
| Conector motor R | 1 | 2 pinos |
| Conector fan/ESC | 1 | 2/3 pinos |
| MOSFET fan | 1 | opcional |
| Diodo flyback | 1 | motor DC |
| J1/J2 board-to-board | 2 | brain |
| Conector sensor | 1 | HDB-101 |
| Test points | 8–12 | debug |

Notas HDB-100:

- `JBAT`, `J_ML` e `J_MR` usam footprint placeholder
  `PowerConnector_1x02_3p5`; substituir pelo conector real antes de Gerber.
- `SW_PWR` usa `SlideSwitch_SPST_8x4`; confirmar corrente e fixacao mecanica.
- `CBULK1` usa `BulkCap_Radial_D10_P5`; confirmar diametro, altura e colisao
  com bateria/Brain Board.
- `J_FAN` esta como header 1x04: `VMOTOR`, `GND`, `FAN_PWM`, `5V_IN`; ajustar
  quando fan/ESC real for escolhido.

## HDB-101

| Item | Qtd | Observação |
|---|----:|---|
| Sensor vermelho 8 canais | 1 | Rev A0 |
| Sensor lateral | 2 | se usados |
| Conector | 1 | flat/JST/header |

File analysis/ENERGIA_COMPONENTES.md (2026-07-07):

# Análise de Energia e Componentes - PEGASUS

Nota: estimativa preliminar para orientar escolhas de bancada. Preços, massas,
correntes e capacidade de bateria precisam ser confirmados com componentes reais
antes de virarem BOM final ou criterio de competicao.

**Data:** 2025-02-20 | **Equipe:** PEGASUS (Seguidor de Linha) | **Hardware Base:** STM32F411 + ESP32-S3, TB6612FNG, 2x N20, 2S LiPo

---

## 1. ORÇAMENTO DE CORRENTE POR TRILHO

### Cenário VBAT (Bateria 2S Direto)

| Condição | Corrente | Descrição |
|---|---|---|
| No-load | 0.20 A | 2× N20 em repouso |
| Típico corrida | 2.8 A | 2× N20 (0.4A cada) + EDF (2.0A min) |
| Pico | 9.2 A | 2× N20 stall (1.6A cada) + EDF máx (6.0A) |

### Cenário 5V (Buck Mini360)

| Condição | Corrente | Componentes |
|---|---|---|
| Base | 0.060 A | STM32F411 + TB6612 lógica |
| WiFi + sensores | 0.430 A | + ESP32-S3 WiFi avg + 10× IR LEDs ligados |
| Pico TX | 0.660 A | WiFi peak (350mA) + IR ligados |

**Análise Mini360:**
- Contínuo: 1.0 A (suficiente para 0.430 A típico)
- Pico: 2.5 A (suficiente para 0.660 A)
- **Conclusão:** Mini360 OK, mas margem apertada. Se IR sempre ligados causarem problemas, implementar PWM dos LEDs (ligar só durante leitura ADC ~5ms a cada 50ms).

---

## 2. ANÁLISE DE BATERIA (2S LiPo)

### Especificações de Candidatas

| Capacidade | C-rate | Max Contínuo | Sag @13A | Massa | Status |
|---|---|---|---|---|---|
| 300 mAh | 25C | 7.5 A | 1.32 V | 15.2 g | INSUFICIENTE |
| 300 mAh | 50C | 15.0 A | 0.92 V | 15.2 g | ✓ |
| 450 mAh | 25C | 11.2 A | 1.32 V | 15.3 g | INSUFICIENTE |
| 450 mAh | 50C | 22.5 A | 0.92 V | 15.3 g | ✓ |
| 650 mAh | 25C | 16.2 A | 1.32 V | 15.5 g | ✓ |
| 650 mAh | 50C | 32.5 A | 0.92 V | 15.5 g | ✓ |

### Estimativa de Sag de Tensão

**Fórmula:** V_sag = I_pico × R_interna

- **450 mAh 50C:** R_int ≈ 70 mΩ → Sag @13A = 0.92 V (7.5V mínimo, aceitável)
- **650 mAh 25C:** R_int ≈ 100 mΩ → Sag @13A = 1.32 V (7.08V mínimo, crítico)

### Autonomia Estimada

- **Corrida típica:** 3.8 A @ VBAT × 60 s = 0.063 Ah consumido
- **450 mAh @ 50C:** ~6 corridas (6 min total) antes de troca
- **Recomendação:** **450 mAh 50C** (melhor balanço massa/performance)

### Proteção em Firmware

```
LOW_VOLTAGE_CUTOFF = 3.3V por célula (6.6V para 2S)
- Implementar monitoramento ADC de VBAT
- Hard-stop de motores se V_cell < 3.2V
```

---

## 3. QUALIDADE ANALÓGICA - Ruído Motor/Buck nos Canais ADC

### Problema

- **TB6612FNG PWM:** ~20 kHz (gera harmônicos até 1 MHz)
- **Mini360 buck:** ~340 kHz (ripple característico)
- **IR LEDs:** Corrente pulsada → acoplamento capacitivo em PA0-PA7

### Solução: Filtro RC por Canal

**Frequência de corte alvo:** 10 kHz (atenua ruído de chaveamento, preserva leitura sensores)

**Cálculo:**
```
f_c = 1 / (2π × R × C)
C = 1 / (2π × 10kHz × 10kΩ) ≈ 1.6 nF → usar 10 nF (E12)
```

**Componentes por canal:** R = 10 kΩ, C = 10 nF

### Checklist Plano Analógico (para Codex/KiCAD)

- [ ] **Filtro RC (10k + 10nF)** em cada entrada: PA0, PA1, PA2, PA3, PA4, PA5, PA6, PA7
- [ ] **Capacitor 100nF desacoplamento** próximo a cada sensor (máx 2cm de fio)
- [ ] **Plano GND contínuo** — sem cortes sob drivers/buck
- [ ] **Trilho 5V (buck) isolado** de VBAT (retornos separados até star point)
- [ ] **Estrela de GND:** ponto único de retorno para VBAT, 5V, sensores
- [ ] **Cabo VBAT blindado** de bateria até TB6612 (XT30 → PCB)
- [ ] **Via tecelada** em volta de PA0-PA7 (ligação GND próxima)

---

## 4. SELEÇÃO DE COMPONENTES - PREÇOS BRASIL/ALIEXPRESS

### Rodas de Silicone

| Opção | Preço Estimado | Massa | Nota |
|---|---|---|---|
| **Silicone 26 mm** | R$ 25–35 un | 4 g un | Menor inércia, mais rápido |
| Silicone 32 mm | R$ 35–50 un | 7 g un | Maior tração, mais peso |

**Recomendação:** 26 mm (4 un = R$ 100–140, 16 g total)

### Ventoinha de Sucção

| Opção | Preço | Massa | Consumo | Vantagem |
|---|---|---|---|---|
| **Blower 5V 3010** | R$ 45–60 | 28 g | 0.2–0.4 A | Direto em buck, simples |
| Axial 4020 12V | R$ 35–50 | 35 g | ~0.3 A @ 8.4V | Menos potência em 2S |
| EDF 30mm + ESC30A | R$ 180–220 | 92 g | 2–6 A | Máxima sucção, peso alto |

**Recomendação:** **Blower 5V 3010** (custo-benefício, baixo consumo 5V)

### Sensores Frontais

| Opção | Preço | Massa | Acurácia | Nota |
|---|---|---|---|---|
| **Barra IR 8ch PCB** | R$ 45 | 12 g | ±2° | Atual, validado |
| QTR-8A Pololu | R$ 120 | 8 g | ±0.5° | Comercial, mais preciso |

**Recomendação:** Manter **8ch PCB** (custo 3×, massa -4g insuficiente para justificar)

### Conectores e Chave

| Item | Opção | Preço | Massa |
|---|---|---|---|
| **Bateria** | XT30 macho/fêmea | R$ 8–12/par | 1.2 g par |
| **Liga/Desliga** | Chave micro 2P deslizante | R$ 10–15 | 3 g |

### IMU Opcional (Ajuda em Curva)

| Chip | Preço | Massa | Interface | Nota |
|---|---|---|---|---|
| MPU6050 | R$ 20–30 | 4 g | I2C | 6-DOF, viável |
| ICM42688 | R$ 35–50 | 3.5 g | SPI/I2C | 6-DOF, melhor ruído |

**Recomendação:** IMU **opcional** em Rev 2 (teste estabilidade sem antes)

---

## 5. TABELA FINAL DE POTÊNCIA

### Cenário de Corrida Típica (60 segundos)

**Condição:** Velocidade média, motores 40% PWM + EDF 3.0 A (média entre mín/máx)

| Trilho | Corrente | Tensão | Potência |
|---|---|---|---|
| VBAT | 3.80 A | 8.4 V | 31.9 W |
| 5V | 0.43 A | 5.0 V | 2.15 W |
| **TOTAL** | — | — | **34.1 W** |

### Energia por Corrida

- **Duração:** 60 segundos
- **Energia consumida:** 34.1 W × 60 s ÷ 3600 = **0.568 Wh**
- **Bateria 450 mAh @ 8.4 V:** 3.78 Wh
- **Autonomia:** 3.78 ÷ 0.568 ≈ **6.6 corridas** (≈ 6–7 minutos total)

### Margem de Segurança

| Aspecto | Valor | Status |
|---|---|---|
| Corrente pico estimada | 9.2 A | 70% da capacidade bateria 450mAh 50C ✓ |
| Sag mínimo em pico | 7.5 V | Acima do limite STM32 (6.3V) ✓ |
| Tempo entre trocas | ~7 min | Aceitável para sessão de testes |
| Peso total estimado | ~280 g | Dentro de margens (com blower) |

---

## 6. RECOMENDAÇÕES PARA O CODEX (BOM/PCB)

### Decisões Estruturais

- **Buck:** Manter Mini360 (5V/1A), validado, backup: TPS563201 (2A, síncrono) se futuro requerer
- **Bateria:** **450 mAh 50C** (balance peso/potência, ~R$ 60–80)
- **Ventoinha:** **Blower 5V 3010** (R$ 50–60, 0.3A integrado ao 5V)
- **Rodas:** Silicone 26 mm (R$ 120–140 set 4un)

### PCB/Analógico (Imediato para Rev 1.1)

- [ ] Adicionar filtro RC **10k + 10nF** em **PA0–PA7** (8 canais motores + 2 sensores laterais)
- [ ] **100nF desacoplamento** imediato na entrada de cada sensor IR (máx 2 cm)
- [ ] Separar retorno **5V (buck)** de **VBAT** até ponto único no conector de bateria (star point GND)
- [ ] Blindagem ou tweits em **VBAT → TB6612** (reduz acoplamento capacitivo)
- [ ] Plano GND contínuo, sem cortes

### Firmware (Próximos Sprints)

- [ ] **ADC:** ativar averaging (4–8 amostras) + filtro FIR na leitura IR
- [ ] **PWM IR LEDs:** ligar só durante janela ADC (5–10 ms a cada 50 ms) → reduz consumo 5V para ~250 mA
- [ ] **Monitoramento VBAT:** ADC entrada + firmware cutoff 3.3V/célula (6.6V 2S)
- [ ] **Telemetria:** logar potência/corrente para validação em campo

### Massa Estimada (Sem Chassis)

| Subsistema | Massa |
|---|---|
| Bateria 450mAh | 15.3 g |
| Blower + duct | 40 g |
| Rodas (4×) | 16 g |
| Motores N20 | 20 g |
| PCB + eletrônica | 35 g |
| Conector/chave | 5 g |
| **TOTAL** | **~131 g** |
| + Chassis alumínio | ~120–150 g |
| **FINAL** | **~250–280 g** |

---

## Referências de Cálculo

- **Motor N20 6V 1000rpm:** I_no_load=0.1A, I_típico=0.4A, I_stall=1.6A (datasheet genérico)
- **TB6612FNG:** PWM ~20 kHz, dropout ~0.5V @ 2A
- **Mini360:** 1.0 A contínuo, 2.5 A pico, R_int ~100 mΩ, dropout ~0.3V
- **2S LiPo 450mAh 50C:** R_int ~70 mΩ, sag=13A×0.07Ω=0.91V
- **ESP32-S3 WiFi AP:** 120 mA média, 350 mA pico TX

---

**Próximas Ações:**
1. Fabricar nova PCB Rev 1.1 com filtros RC analógicos
2. Testar consumo 5V com PWM IR (expectativa: -50 mA)
3. Validar sag de tensão em corrida com osciloscopio
4. Avaliar IMU (MPU6050) em Rev 2 se estabilidade exigir

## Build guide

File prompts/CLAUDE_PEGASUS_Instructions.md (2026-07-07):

# CLAUDE.md — Instruções para Claude Code no Projeto PEGASUS

Projeto: **PEGASUS Line Follower Robot**  
Equipe/Marca: **Hander / PEGASUS**  
Responsável: **Wesley Mateus Basso**  
Função deste arquivo: orientar o **Claude Code** a trabalhar corretamente no repositório, sem quebrar a arquitetura do projeto.

---

## 1. Papel do Claude Code

Você é o **engenheiro de implementação local** do projeto PEGASUS.

Sua função é:

- criar a estrutura do repositório;
- implementar código de forma modular;
- organizar arquivos;
- refatorar com segurança;
- corrigir erros de build;
- criar testes;
- documentar decisões técnicas;
- respeitar a arquitetura definida nos arquivos `.md`.

Você **não é o arquiteto principal** do projeto. Antes de tomar decisões grandes, leia a documentação e registre dúvidas.

---

## 2. Arquitetura geral do PEGASUS

O PEGASUS é um robô seguidor de linha competitivo com:

```text
STM32F411 = piloto em tempo real
ESP32-S3  = interface, telemetria, logs, configuração e análise
```

### STM32F411

Responsável por:

- leitura ADC dos sensores;
- calibração dos sensores;
- normalização dos sensores;
- detecção de linha;
- detecção de cruzamento;
- máquina de estados principal;
- controle PD/PID;
- PWM real dos motores;
- PWM real da sucção;
- segurança crítica;
- watchdog;
- comunicação UART com ESP32.

### ESP32-S3

Responsável por:

- dashboard web;
- Wi-Fi Access Point;
- UART com STM32;
- envio de comandos;
- recebimento de telemetria;
- configuração de PID;
- configuração de PWM dos motores;
- configuração de PWM da sucção;
- logs;
- perfis;
- diagnóstico;
- sugestões automáticas.

---

## 3. Regra de ouro

```text
O STM32 controla.
O ESP32 observa, configura e comunica.
```

Nunca coloque no ESP32:

- PID principal;
- PWM real dos motores;
- controle crítico de linha;
- decisão crítica de segurança;
- leitura principal dos sensores;
- máquina de estados principal do robô.

Nunca coloque no STM32:

- dashboard web;
- Wi-Fi;
- lógica pesada de análise pós-corrida;
- armazenamento complexo de logs de alto nível;
- interface de usuário.

---

## 4. Documentos que devem ser lidos primeiro

Antes de escrever código, leia todos os `.md` relevantes no repositório.

Prioridade:

```text
1. HFS-STM32-001_PEGASUS_STM32_Control_Firmware_RevA0_1.md
2. HFS-ESP32-001_PEGASUS_ESP32_Configuration_RevA0_1.md
3. DECISIONS.md
4. TASKS.md
5. AGENTS.md
6. TEST_PLAN.md
```

Se algum desses arquivos não existir, crie apenas os arquivos estruturais básicos e registre pendência em:

```text
DECISIONS_PENDING.md
```

---

## 5. Não inventar pinagem

Não assuma pinos reais sem confirmação.

Se a pinagem ainda não estiver definida, use:

```c
#define PIN_TODO -1
```

ou comentários claros:

```c
// TODO: confirmar pino físico na placa final
```

Isso vale especialmente para:

- ESP32-S3 Zero;
- Seeed XIAO ESP32-S3;
- Black Pill STM32F411;
- TB6612;
- FAN_PWM;
- ADC dos sensores;
- UART STM32 ↔ ESP32.

---

## 6. Hardware atual e fases do projeto

### Fase 0 — Protoboard

Usar:

- STM32 Black Pill F411;
- ESP32-S3 Zero;
- protoboard/jumpers;
- alimentação por USB separada;
- GND comum.

Objetivo:

```text
validar comunicação UART, dashboard e comandos sem arriscar o Seeed XIAO.
```

### Fase 1 — Carrinho de teste

Usar:

- STM32 Black Pill;
- ESP32-S3 Zero;
- TB6612;
- sensores analógicos;
- motores N20;
- bateria 2S;
- buck 5V.

### Fase 2 — Placa oficial

Usar:

- HDB-001 Brain Board;
- Seeed XIAO ESP32-S3;
- HDB-100 Chassis / Power Board;
- HDB-101 Sensor Board.

---

## 7. Estrutura esperada do repositório

Crie ou respeite esta estrutura:

```text
PEGASUS/
├── CLAUDE.md
├── AGENTS.md
├── CODEX.md
├── DECISIONS.md
├── DECISIONS_PENDING.md
├── TASKS.md
├── TEST_PLAN.md
├── README.md
├── docs/
│   ├── HFS-STM32-001_PEGASUS_STM32_Control_Firmware_RevA0_1.md
│   └── HFS-ESP32-001_PEGASUS_ESP32_Configuration_RevA0_1.md
├── firmware/
│   ├── stm32/
│   │   ├── Core/
│   │   │   ├── Inc/
│   │   │   └── Src/
│   │   └── README_STM32.md
│   └── esp32/
│       ├── main.cpp
│       ├── app_config.h
│       ├── board_pins.h
│       ├── communication/
│       ├── web/
│       ├── telemetry/
│       ├── config/
│       ├── analysis/
│       ├── safety/
│       └── ota/
├── hardware/
│   ├── HDB-001_Brain_Board/
│   ├── HDB-100_Chassis_Power_Board/
│   └── HDB-101_Sensor_Board/
├── tests/
│   ├── protocol/
│   ├── stm32_logic/
│   └── esp32_logic/
└── tools/
```

---

## 8. Firmware STM32 — regras obrigatórias

O STM32F411 é **single-core Cortex-M4F**, não dual-core.

Para usar o máximo do STM32, utilize:

- ADC em scan mode;
- DMA circular para sensores;
- timers para PWM;
- timer periódico para loop de controle;
- UART com interrupção ou DMA;
- watchdog;
- FPU para PD/PID.

### Loop de controle

Começar com:

```text
500 Hz
```

Depois permitir:

```text
1 kHz
```

O loop deve executar:

1. snapshot dos sensores;
2. filtro;
3. normalização;
4. detecção de eventos;
5. máquina de estados;
6. PD/PID;
7. atualização dos motores;
8. segurança.

### Não bloquear o loop

Evite:

- `delay()`;
- loops de espera;
- escrita serial pesada dentro do controle;
- cálculo pesado dentro de interrupções;
- telemetria em frequência exagerada.

---

## 9. Sensores do STM32

O robô usa sensores analógicos:

```text
S0 S1 S2 S3 S4 S5 S6 S7
LAT_L
LAT_R
```

### Sensores frontais

Servem para:

- seguir linha;
- calcular posição;
- detectar cruzamento;
- detectar linha perdida.

### Sensor lateral esquerdo

```text
LAT_L = marcador de curva esquerda
```

Só vale se não houver cruzamento.

### Sensor lateral direito

```text
LAT_R = marcador de início/parada
```

Só vale se não houver cruzamento.

Regra crítica:

```text
Se LAT_R estiver ativo, mas a frente indicar cruzamento, o evento é CROSSING.
Não é início.
Não é parada.
```

---

## 10. Pipeline dos sensores

Implementar:

```text
ADC cru
 ↓
filtro
 ↓
normalização 0–1000
 ↓
posição da linha
 ↓
detecção de eventos
 ↓
máquina de estados
```

### Normalização

```c
norm[i] = (raw[i] - min[i]) * 1000 / (max[i] - min[i]);
```

Com saturação:

```c
if (norm[i] < 0) norm[i] = 0;
if (norm[i] > 1000) norm[i] = 1000;
```

### Posição da linha

Pesos iniciais:

```text
S0    S1    S2    S3    S4    S5    S6    S7
-3500 -2500 -1500 -500  +500 +1500 +2500 +3500
```

---

## 11. Detecção de cruzamento

Não detectar cruzamento usando lateral.

Cruzamento deve vir dos sensores frontais.

Critérios:

```c
crossing_detected =
    strong_count >= crossing_min_count &&
    span >= crossing_min_span &&
    front_sum >= crossing_sum_threshold;
```

Valores iniciais:

```text
crossing_min_count = 5
crossing_min_span = 5
crossing_sum_threshold = 3500
```

Todos configuráveis pelo ESP32.

Se `crossing_detected == true`:

```text
ignorar LAT_L
ignorar LAT_R
```

---

## 12. Máquina de estados do STM32

Implementar estes estados:

```c
typedef enum {
    ST_BOOT = 0,
    ST_SELF_TEST,
    ST_IDLE,
    ST_CALIBRATION,
    ST_READY,
    ST_ARMED,
    ST_FAN_SPINUP,
    ST_RUNNING,
    ST_CROSSING,
    ST_CURVE_LEFT,
    ST_LINE_LOST,
    ST_FINISH_DETECTED,
    ST_SAFE_STOP,
    ST_HARDWARE_TEST,
    ST_ERROR
} robot_state_t;
```

Fluxo geral:

```text
BOOT
 ↓
SELF_TEST
 ↓
IDLE
 ↓
CALIBRATION
 ↓
READY
 ↓
ARMED
 ↓
FAN_SPINUP
 ↓
RUNNING
 ├── CROSSING
 ├── CURVE_LEFT
 ├── LINE_LOST
 ├── FINISH_DETECTED
 └── SAFE_STOP
```

### Prioridade dentro de RUNNING

```text
1. STOP manual ou emergência
2. Falha crítica
3. Cruzamento frontal
4. Linha perdida
5. Sensor direito de fim/parada
6. Sensor esquerdo de curva
7. Seguimento normal por PD/PID
```

---

## 13. Controle PD/PID

Começar com PD:

```text
Ki = 0
```

Fórmula:

```c
error = target_position - position;
derivative = error - last_error;
correction = kp * error + kd * derivative;
```

PID completo pode existir, mas a integral deve começar desativada.

Integral deve ser congelada ou zerada em:

- cruzamento;
- linha perdida;
- motor saturado;
- safe stop;
- hardware test;
- finish.

---

## 14. Controle dos motores

Motores:

```text
N20 6 V 1000 rpm sem encoder
```

Driver:

```text
TB6612FNG
```

Bateria:

```text
LiPo 2S
```

Como LiPo 2S cheia tem cerca de 8.4 V, limitar PWM inicialmente:

```text
pwm_max = 70% a 75%
```

Cálculo base:

```c
motor_left  = base_speed - correction;
motor_right = base_speed + correction;
```

Aplicar:

- `pwm_min_left`;
- `pwm_min_right`;
- `pwm_max_left`;
- `pwm_max_right`;
- inversão de motor;
- rampa de aceleração;
- rampa de frenagem.

Teste de motor sempre com timeout.

---

## 15. Controle da sucção

A sucção pode ser:

```text
PWM_DC_MOSFET
ESC_SERVO
```

Parâmetros:

```text
fan_pwm_start
fan_pwm_run
fan_pwm_max
fan_start_delay_ms
fan_mode
```

O STM32 gera o PWM real. O ESP32 apenas configura e manda comandos.

---

## 16. Firmware ESP32 — regras obrigatórias

O ESP32-S3 deve usar FreeRTOS com dois cores.

### Core 0

Responsável por:

- UART com STM32;
- parser de pacotes;
- command queue;
- telemetry queue;
- watchdog de comunicação;
- Wi-Fi manager.

### Core 1

Responsável por:

- web dashboard;
- logs;
- perfis;
- NVS;
- análise inteligente;
- sugestões de ajuste.

---

## 17. Suporte a ESP32-S3 Zero e XIAO

Criar no ESP32:

```text
firmware/esp32/board_pins.h
```

Suportar:

```text
BOARD_ESP32_S3_ZERO
BOARD_XIAO_ESP32_S3
```

A primeira implementação deve funcionar no:

```text
ESP32-S3 Zero
```

O XIAO fica preparado para a placa oficial.

Não definir pinos reais sem confirmação.

---

## 18. UART ESP32 ↔ STM32

Usar protocolo comum aos dois firmwares.

Frame:

```text
SOF | TYPE | LEN | PAYLOAD | CRC8
```

```text
SOF = 0xA5
```

Configuração inicial:

```text
115200 8N1
```

Futuro:

```text
921600 8N1
```

Tipos mínimos:

```text
TELEMETRY_BASIC
SENSOR_VALUES
SET_PID
SET_MOTOR_CONFIG
SET_FAN_CONFIG
CALIBRATION_START
CALIBRATION_STOP
START_RUN
STOP_RUN
ARM
DISARM
HARDWARE_TEST
ERROR_STATUS
ACK
NACK
```

---

## 19. Dashboard ESP32

O dashboard deve ter:

- status;
- sensores;
- calibração;
- PID;
- motores;
- sucção;
- eventos;
- perfis;
- logs;
- análise inteligente.

Access Point:

```text
SSID: PEGASUS_SETUP
Senha: pegasus123
IP: 192.168.4.1
```

Botão STOP sempre visível.

---

## 20. Segurança

Sempre priorizar segurança.

### Regras gerais

- Todo teste de motor deve ter timeout.
- Todo teste de fan deve ter timeout.
- STOP deve ser prioridade máxima.
- Não rodar motor automaticamente após boot.
- Não iniciar corrida sem calibração válida.
- Não aplicar sugestões automáticas durante corrida oficial.
- Se houver dúvida, parar motor e registrar erro.

### Se ESP32 falhar

O STM32 deve ter comportamento configurável:

```text
Modo competição: continuar corrida com configuração já carregada.
Modo bancada: parar por segurança se perder ESP32.
```

Parâmetro:

```text
stop_on_esp_timeout
```

---

## 21. Primeira tarefa recomendada para Claude Code

Execute nesta ordem:

### Etapa 1 — preparar repositório

- Criar estrutura de pastas.
- Criar `README.md`.
- Criar `DECISIONS.md`.
- Criar `DECISIONS_PENDING.md`.
- Criar `TASKS.md`.
- Criar `TEST_PLAN.md`.

### Etapa 2 — criar esqueleto STM32

Criar arquivos:

```text
robot_state.h/.c
sensor_processing.h/.c
calibration.h/.c
line_detector.h/.c
pid_controller.h/.c
motor_control.h/.c
fan_control.h/.c
uart_protocol.h/.c
telemetry.h/.c
safety.h/.c
config.h/.c
```

Não implementar motor real ainda. Criar funções base, structs, enums e TODOs.

### Etapa 3 — criar esqueleto ESP32

Criar arquivos:

```text
main.cpp
app_config.h
board_pins.h
communication/uart_protocol.cpp/.h
communication/packet_parser.cpp/.h
web/web_server.cpp/.h
web/api_routes.cpp/.h
telemetry/telemetry_model.cpp/.h
config/config_manager.cpp/.h
analysis/run_analyzer.cpp/.h
safety/stm32_watchdog.cpp/.h
```

Começar com `BOARD_ESP32_S3_ZERO`.

### Etapa 4 — protocolo UART comum

Criar parser robusto com:

- SOF;
- TYPE;
- LEN;
- PAYLOAD;
- CRC8;
- ACK;
- NACK;
- timeout;
- recuperação após byte perdido.

### Etapa 5 — teste fake

Antes de motor real:

```text
STM32 envia telemetria fake.
ESP32 mostra no dashboard.
ESP32 envia START/STOP/ARM/CALIBRATION.
STM32 responde ACK.
```

---

## 22. Como responder após cada tarefa

Depois de modificar arquivos, responda sempre com:

```text
Resumo:
- arquivo X criado
- arquivo Y alterado
- módulo Z implementado

Testes recomendados:
- comando para compilar
- teste manual esperado
- riscos conhecidos

Pendências:
- pino tal precisa confirmar
- módulo tal ainda está mockado
```

---

## 23. O que NÃO fazer

Não faça:

- não criar código monolítico gigante;
- não colocar tudo em `main.c`;
- não usar delay no loop de controle;
- não inventar pinos;
- não misturar STM32 e ESP32;
- não colocar PID no ESP32;
- não colocar Wi-Fi no STM32;
- não iniciar motores sem comando explícito;
- não remover safety para “simplificar”;
- não reescrever arquivos inteiros sem necessidade;
- não ignorar os `.md` de especificação.

---

## 24. Formato de decisões

Se precisar registrar decisão:

```markdown
# DECISIONS.md

## DEC-XXX — Título

Data: AAAA-MM-DD  
Status: Aceita / Pendente / Rejeitada

### Contexto

Explique o problema.

### Decisão

Explique a decisão.

### Consequência

Explique impacto positivo e negativo.
```

Se for dúvida:

```markdown
# DECISIONS_PENDING.md

## PEND-XXX — Título

### Dúvida

Explique a dúvida.

### Opções

1. Opção A
2. Opção B

### Recomendação

Sugira uma opção, mas não implemente até confirmação.
```

---

## 25. Tarefas iniciais sugeridas

Crie um `TASKS.md` com:

```markdown
# TASKS.md — PEGASUS

## Fase 0 — Protoboard

- [ ] Criar estrutura do repositório.
- [ ] Criar protocolo UART comum.
- [ ] Implementar CRC8.
- [ ] Implementar parser de pacotes.
- [ ] Implementar telemetria fake no STM32.
- [ ] Implementar dashboard mínimo no ESP32-S3 Zero.
- [ ] Testar PING/PONG.
- [ ] Testar START/STOP/ARM/CALIBRATION.
- [ ] Exibir sensores fake no dashboard.
- [ ] Preparar leitura ADC real.
- [ ] Preparar hardware test com timeout.

## Fase 1 — Carrinho de teste

- [ ] Ler sensores analógicos reais.
- [ ] Calibrar sensores.
- [ ] Normalizar 0–1000.
- [ ] Implementar detecção de cruzamento.
- [ ] Implementar regra LAT_R inválido em cruzamento.
- [ ] Implementar PD.
- [ ] Testar TB6612 com rodas suspensas.
- [ ] Testar linha em baixa velocidade.

## Fase 2 — Placa oficial

- [ ] Migrar ESP32-S3 Zero para Seeed XIAO ESP32-S3.
- [ ] Confirmar pinagem HDB-001.
- [ ] Validar conectores JF/JR.
- [ ] Validar HDB-100.
- [ ] Validar HDB-101.
```

---

## 26. Prompt operacional curto para Claude Code

Use este modo de trabalho:

```text
Leia CLAUDE.md e todos os documentos .md do projeto PEGASUS.

Você deve atuar como engenheiro de implementação local.

Primeiro, crie ou organize a estrutura do repositório.
Depois, implemente apenas esqueletos modulares dos firmwares STM32 e ESP32, respeitando a separação:
- STM32 = controle em tempo real
- ESP32 = interface e telemetria

Não implemente controle real de motor ainda.
Não invente pinagem.
Não coloque PID no ESP32.
Não coloque Wi-Fi no STM32.

Crie TODOs claros onde faltar informação.
Ao final, liste arquivos criados, arquivos alterados, testes recomendados e pendências.
```

---

## 27. Objetivo final da Fase 0

A Fase 0 estará concluída quando:

```text
ESP32-S3 Zero cria Wi-Fi PEGASUS_SETUP.
Dashboard abre em 192.168.4.1.
STM32 Black Pill comunica via UART.
ESP32 envia comandos.
STM32 responde ACK.
STM32 envia telemetria fake.
Dashboard mostra estado e sensores fake.
STOP funciona.
Nenhum motor é acionado automaticamente.
```

Somente depois disso o projeto deve avançar para sensores reais e motores.

---

## 28. Princípio de engenharia do projeto

```text
Primeiro comunicar.
Depois medir.
Depois controlar.
Depois acelerar.
```

Não pule etapas.

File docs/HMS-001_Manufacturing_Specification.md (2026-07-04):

# HMS-001 — Manufacturing Specification

Projeto: PEGASUS  
Revisão: A0

## 1. PCB

- FR4.
- 1.6 mm.
- 2 camadas.
- Cobre 1 oz.
- Silkscreen branco.
- Máscara preta se custo permitir.

## 2. Regras de potência

- Trilhas de bateria/motor: mínimo 2.0 mm; preferir polígonos.
- Capacitor bulk próximo da entrada XT30.
- Capacitor próximo do TB6612.
- Buck perto da entrada, mas longe dos sinais analógicos.
- Corrente alta não deve passar pela Brain Board.

## 3. Regras de sinal

- Sinais A0–A7 longe de motor, buck e FAN.
- UART curta e com GND próximo.
- Test points:
  - VBAT
  - 5V
  - 3V3
  - GND
  - PWMA
  - PWMB
  - STBY
  - FAN_PWM
  - UART TX/RX

## 4. Mecânica

- Confirmar todos os footprints com paquímetro.
- Confirmar altura entre placas.
- Confirmar acesso ao USB-C do XIAO.
- Confirmar posição da bateria.
- Confirmar furo da ventosa.

## 5. Checklist antes de fabricar

- [ ] ERC sem erro crítico.
- [ ] DRC sem erro crítico.
- [ ] Gerbers conferidos.
- [ ] Drill conferido.
- [ ] Silkscreen conferido.
- [ ] Pin 1 de todos conectores identificado.
- [ ] Polaridade XT30 e motores conferida.

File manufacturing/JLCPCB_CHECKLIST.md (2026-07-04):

# JLCPCB / PCBWay Checklist

## Medir antes

- [ ] Black Pill.
- [ ] XIAO.
- [ ] TB6612.
- [ ] Mini360.
- [ ] Sensor vermelho.
- [ ] Bateria.
- [ ] Motores N20.
- [ ] Motor/ventosa.

## Elétrica

- [ ] Pinagem TB6612.
- [ ] Pinagem XIAO.
- [ ] UART STM32 ↔ ESP32.
- [ ] 5V/3V3.
- [ ] GND comum.
- [ ] Polaridade XT30.
- [ ] Polaridade motores.
- [ ] FAN_PWM.

## KiCad

- [ ] ERC.
- [ ] DRC.
- [ ] Footprints.
- [ ] Silkscreen.
- [ ] Furos.
- [ ] Gerber viewer.

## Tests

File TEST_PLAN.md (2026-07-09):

# TEST_PLAN.md - Plano De Testes PEGASUS Rev A0

Atualizado: 2026-07-08.

## Principios

- Enquanto nao houver hardware fisico, testar apenas consistencia KiCad/docs.
- Primeiro testar sem motores e sem succao.
- Depois testar potencia com fonte limitada.
- Depois motores com rodas suspensas.
- Depois succao isolada.
- So depois colocar no chao, em velocidade baixa.
- `STOP_RUN` precisa funcionar em todas as fases com atuadores.

## F-KiCad - Sem Hardware Fisico

Objetivo: preparar a Rev A0 para revisao humana sem gerar Gerber.

Testes:

- Conferir balanceamento de parenteses dos arquivos `.kicad_pcb` e
  `.kicad_mod`.
- Conferir se todo placeholder novo esta listado em BOM e pendencias.
- Conferir se `VBAT_RAW` e `VMOTOR` nao foram misturados sem chave.
- Conferir visualmente se bateria, chave, XT30, capacitor e conectores estao
  em regioes plausiveis.
- Confirmar que documentos continuam dizendo que Gerber final esta bloqueado.

Sucesso:

- KiCad abre os projetos.
- Nomes de nets e referencias sao legiveis.
- Toda decisao sem medida real aparece em `DECISIONS_PENDING.md`.

## F0 - Protoboard Sem Motores

Objetivo: validar ESP32 <-> STM32.

Testes:

- ESP32 AP `PEGASUS_SETUP` abre dashboard em `192.168.4.1`.
- UART 115200 8N1 entre ESP32-S3-Zero GPIO43/44 e STM32 PA10/PA9 com GND comum.
- `PING/PONG` por 1000 ciclos.
- CRC invalido gera rejeicao controlada.
- Comandos validos geram `ACK`; comandos invalidos geram `NACK`.
- Telemetria fake aparece no dashboard por 10 minutos sem travar.

Sucesso:

- Sem reset espontaneo.
- Sem perda de link recorrente.
- Ultimo ACK/NACK e idade da telemetria visiveis.

## F1 - Sensores

Objetivo: validar sensores frontais e laterais.

Testes:

- Ler raw de A0-A7 e laterais.
- Calibrar fundo e linha.
- Verificar normalizacao 0-1000.
- Validar linha perdida, cruzamento e lateral direita/esquerda.
- Medir ruido com motores e buck desligados, depois ligados.

Sucesso:

- Cada canal muda claramente com contraste.
- Thresholds sao reproduziveis.
- Ruido nao confunde linha com cruzamento.

## F2 - Potencia Sem Carga

Objetivo: validar alimentacao antes de motores.

Testes:

- Usar fonte de bancada limitada no lugar da LiPo.
- Conferir 5V, 3V3, GND comum e queda de tensao.
- Medir PWM/STBY do TB6612 e FAN_PWM no osciloscopio.
- Confirmar TB6612 em standby no boot.

Sucesso:

- Tensoes dentro da margem.
- Sem aquecimento anormal de buck.
- Nenhum atuador liga sozinho.

## F3 - Motores Suspensos

Objetivo: validar TB6612 e motores N20 sem tocar o chao.

Testes:

- Rodas no ar.
- PWM baixo.
- Sentido esquerda/direita.
- Brake/coast.
- STOP imediato.
- Corrente de stall por teste curto e controlado.

Sucesso:

- Sentido correto.
- STOP corta imediatamente.
- Corrente e temperatura dentro da margem.

## F4 - Succao Isolada

Objetivo: validar fan/EDF/ESC sem tracao.

Testes:

- Sem motores de tracao.
- Corrente medida.
- Spin-up controlado.
- FAN_PWM validado.
- Protecao mecanica do rotor/duto.

Sucesso:

- Sem brownout.
- Sem vibracao excessiva.
- Corrente dentro da capacidade do sistema.

## F5 - Integracao Suspensa

Objetivo: sensores + motores + succao com rodas no ar.

Testes:

- `ARM -> FAN_SPINUP -> RUNNING -> SAFE_STOP`.
- Telemetria em tempo real.
- STOP em todos os estados ativos.
- Logs coerentes.

Sucesso:

- Sem reset.
- Sem estado incoerente.
- Atuadores obedecem safety.

## F6 - Primeira Pista Lenta

Objetivo: seguir linha de forma controlada.

Testes:

- Perfil SAFE.
- Base speed baixo.
- Succao desligada ou baixa.
- Linha reta e curva simples.

Sucesso:

- Segue linha.
- Para seguro ao perder linha.
- Nao satura motor de forma permanente.

## F7 - Pre-Competicao

Objetivo: repetibilidade.

Testes:

- 5 a 10 voltas.
- Bateria cheia e meia carga.
- Temperatura de TB6612, buck, motores, bateria e succao.
- Revisao mecanica apos cada run.

Sucesso:

- Comportamento repetivel.
- Logs completos.
- Sem aquecimento perigoso.

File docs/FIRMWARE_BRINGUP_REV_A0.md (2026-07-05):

# PEGASUS Firmware Bring-up Rev A0.1

## Objetivo

Validar primeiro em bancada:

```text
ESP32-S3 Zero <-> UART <-> STM32 Black Pill
```

Depois migrar o mesmo firmware ESP32 para o XIAO ESP32-S3 na HDB-001.

## Ligacao UART Inicial

STM32 Black Pill:

- `PA9` = `STM32_TX`
- `PA10` = `STM32_RX`
- `GND` comum obrigatorio

ESP32-S3 Zero:

- usar o pad marcado `RX` / `GPIO44` para receber `STM32_TX / PA9`
- usar o pad marcado `TX` / `GPIO43` para transmitir para `STM32_RX / PA10`

Regra:

```text
STM32 PA9 TX  -> ESP32 RX / GPIO44
STM32 PA10 RX <- ESP32 TX / GPIO43
GND           <-> GND
```

## Pinagem ESP32-S3 Zero

A documentacao da Waveshare informa que os pads serigrafados `TX` e `RX` sao:

```cpp
#define STM32_UART_TX_PIN 43
#define STM32_UART_RX_PIN 44
```

O XIAO ESP32-S3 continua pendente porque ainda falta confirmar a variante exata.

## Sequencia De Testes

1. Build ESP32 para `esp32-s3-zero`.
2. Gravar ESP32 ainda sem UART, abrir AP `PEGASUS_SETUP`.
3. Confirmar dashboard em `192.168.4.1`.
4. Testar `PING/PONG`.
5. Testar telemetria fake do STM32.
6. Testar sensores reais.
7. Testar motores com rodas suspensas.
8. Testar succao isolada medindo corrente.

## Referencias

- Waveshare ESP32-S3-Zero wiki: `TX = GPIO43`, `RX = GPIO44`, WS2812 em `GPIO21`, BOOT em `GPIO0`.
- DeepBlueEmbedded STM32F411 Black Pill: confirma Black Pill STM32F411CEU6, 20x2 headers, ADC, timers e USARTs; pinout por diagrama WeAct.

## Comandos Uteis

Build ESP32:

```powershell
cd firmware\esp32
pio run
```

Checar sintaxe STM32:

```powershell
arm-none-eabi-gcc -std=c11 -Wall -Wextra -I firmware\stm32\Core\Inc -fsyntax-only firmware\stm32\Core\Src\*.c
```

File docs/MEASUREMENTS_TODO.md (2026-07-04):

# Measurement Sheet — preencher antes do KiCad final

Use paquímetro e preencha em mm.

| Item | Comprimento | Largura | Altura | Observações |
|---|---:|---:|---:|---|
| Black Pill STM32F411 | | | | |
| XIAO ESP32-S3 / Plus | | | | |
| TB6612FNG módulo | | | | |
| Mini360 buck | | | | |
| Sensor vermelho 8 canais | | | | |
| Bateria LiPo 2S | | | | |
| Motor N20 | | | | |
| Roda | | | | |
| Motor/EDF sucção | | | | |
| Duto/ventosa | | | | |

## Furos

| Item | Diâmetro | Distância X | Distância Y |
|---|---:|---:|---:|
| Black Pill | | | |
| XIAO | | | |
| TB6612 | | | |
| Sensor Board | | | |
| Chassi | | | |

## Decisões após medir

- [ ] Definir largura final do chassi.
- [ ] Definir comprimento final do chassi.
- [ ] Definir altura entre placas.
- [ ] Definir bateria final.
- [ ] Definir motor de sucção.

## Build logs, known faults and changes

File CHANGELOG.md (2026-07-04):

# Changelog

## 2026-07-04 — Pacote inicial PEGASUS Codex

- Estrutura inicial.
- Prompt mestre.
- Especificações HRS/RRS/HPS/HDR/HMS/HFS.
- BOM preliminar.
- Plano KiCad.
- Checklist JLCPCB.

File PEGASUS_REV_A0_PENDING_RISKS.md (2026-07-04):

# PEGASUS Rev A0 - Pendencias e Riscos KiCad

Status: base KiCad mecanica criada. Nao gerar Gerbers finais sem revisao humana.

## Implementado

- Tres projetos KiCad separados:
  - HDB-001_Brain_Board
  - HDB-100_Chassis_Power_Board
  - HDB-101_Sensor_Board
- Biblioteca local `hardware/lib/PEGASUS_Placeholders.pretty`.
- Footprints placeholder:
  - Black Pill 53 x 21 mm.
  - XIAO ESP32-S3 21 x 18 mm.
  - TB6612 module 20 x 20 mm.
  - Mini360 17 x 11 mm.
  - Bateria LiPo 70 x 38 x 18 mm.
  - Ventosa/duto Ø22 mm.
  - J1/J2 2x6 2.54 mm.
- Outlines iniciais:
  - HDB-001: 75 x 40 mm.
  - HDB-100: 182 x 78 mm maximo, corpo traseiro largo e frente estreita.
  - HDB-101: 90 x 18 mm.
- Net labels J1/J2 conforme HPS-001.

## Pendencias antes de roteamento

- Confirmar pinagem fisica real da Black Pill STM32F411CEU6 usada.
- Confirmar se o modulo XIAO sera ESP32-S3 ou ESP32-S3 Plus; dimensoes/pinos podem mudar.
- Confirmar pinagem real do modulo TB6612FNG comprado.
- Definir medicao de bateria: divisor no ESP32, ADC externo ou revisao futura.
- Definir conectores reais de motor, fan/ESC, sensor e XT30.
- Definir se sensores laterais LAT_L/LAT_R serao analogicos ou digitais.
- Revisar acesso mecanico a USB-C, botoes boot/reset e SWD.
- Validar altura de bateria, spacers e folga entre HDB-001 e HDB-100.
- Definir motor/EDF/ESC de succao e corrente esperada.

## Riscos Rev A0

- TB6612 pode nao suportar corrente de stall dos motores escolhidos.
- LiPo 2S cheia tem 8.4 V; firmware deve limitar PWM para motores 6 V.
- Buck Mini360 precisa margem termica e corrente suficiente para logica/sensores.
- Ruido de motor/buck/fan pode contaminar A0-A7 se o roteamento misturar analogico e potencia.
- Duto Ø22 mm pode conflitar com bateria, fan, fixacao ou centro de massa.
- Board-to-board 2x6 precisa altura e alinhamento mecanico validados com spacers reais.
- HDB-100 ainda esta mecanica/posicional, nao e layout eletrico roteado.

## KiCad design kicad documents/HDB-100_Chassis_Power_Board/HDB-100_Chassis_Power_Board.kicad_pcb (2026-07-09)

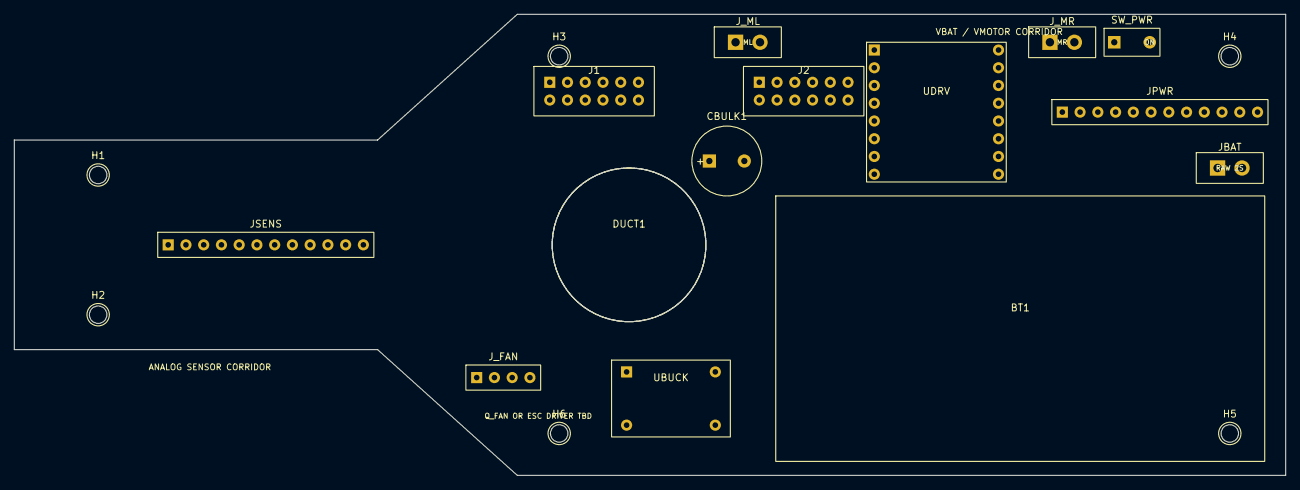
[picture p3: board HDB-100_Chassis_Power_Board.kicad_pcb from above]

Board: 2 copper layers, 182.0 x 66.0 mm, 20 parts (0 on the bottom side), 28 nets, no tracks yet.

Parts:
BT1: LiPo 2S 70x38x18; LiPo_2S_Battery_70x38
CBULK1: 470-1000uF placeholder; BulkCap_Radial_D10_P5
DUCT1: Suction duct D22; Suction_Hole_D22
H1, H2, H3, H4, H5, H6: M2.5; MountingHole_2p5_NPTH
J1: B2B Sensors/Logic; B2B_2x6_2p54
J2: B2B Commands/Power; B2B_2x6_2p54
JBAT: XT30 LiPo 2S placeholder; PowerConnector_1x02_3p5
JPWR: Power IO placeholder; PinHeader_1x12_2p54
JSENS: Sensor Board; PinHeader_1x12_2p54
J_FAN: Fan/ESC placeholder; PinHeader_1x04_2p54
J_ML: Motor L placeholder; PowerConnector_1x02_3p5
J_MR: Motor R placeholder; PowerConnector_1x02_3p5
SW_PWR: Power switch placeholder; SlideSwitch_SPST_8x4
UBUCK: Mini360 5V buck; Mini360_Buck_17x11
UDRV: TB6612FNG module TBD pinout; TB6612_Module_20x20

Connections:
3V3: J1.1, JSENS.1
5V_IN: J2.3, JPWR.3, J_FAN.4, UBUCK.3, UDRV.12
A0: J1.3, JSENS.3
A1: J1.4, JSENS.4
A2: J1.5, JSENS.5
A3: J1.6, JSENS.6
A4: J1.7, JSENS.7
A5: J1.8, JSENS.8
A6: J1.9, JSENS.9
A7: J1.10, JSENS.10
AIN1: J2.6, UDRV.2
AIN2: J2.7, UDRV.3
AOUT1: JPWR.5, J_ML.1, UDRV.7
AOUT2: JPWR.6, J_ML.2, UDRV.8
BIN1: J2.9, UDRV.14
BIN2: J2.10, UDRV.13
BOUT1: JPWR.7, J_MR.1, UDRV.10
BOUT2: JPWR.8, J_MR.2, UDRV.9
FAN_PWM: J2.12, JPWR.9, J_FAN.3
GND: CBULK1.2, J1.2, J2.2, J2.4, JBAT.2, JPWR.2, JPWR.4, JPWR.10, JSENS.2, J_FAN.2, UBUCK.2, UBUCK.4, UDRV.6, UDRV.11
LAT_L: J1.11, JSENS.11
LAT_R: J1.12, JSENS.12
PWMA: J2.5, UDRV.1
PWMB: J2.8, UDRV.15
STBY: J2.11, UDRV.4
VBAT_ADC: J2.1, JPWR.12
VBAT_RAW: JBAT.1, SW_PWR.1
VMOTOR: CBULK1.1, JPWR.1, JPWR.11, J_FAN.1, SW_PWR.2, UBUCK.1, UDRV.5, UDRV.16

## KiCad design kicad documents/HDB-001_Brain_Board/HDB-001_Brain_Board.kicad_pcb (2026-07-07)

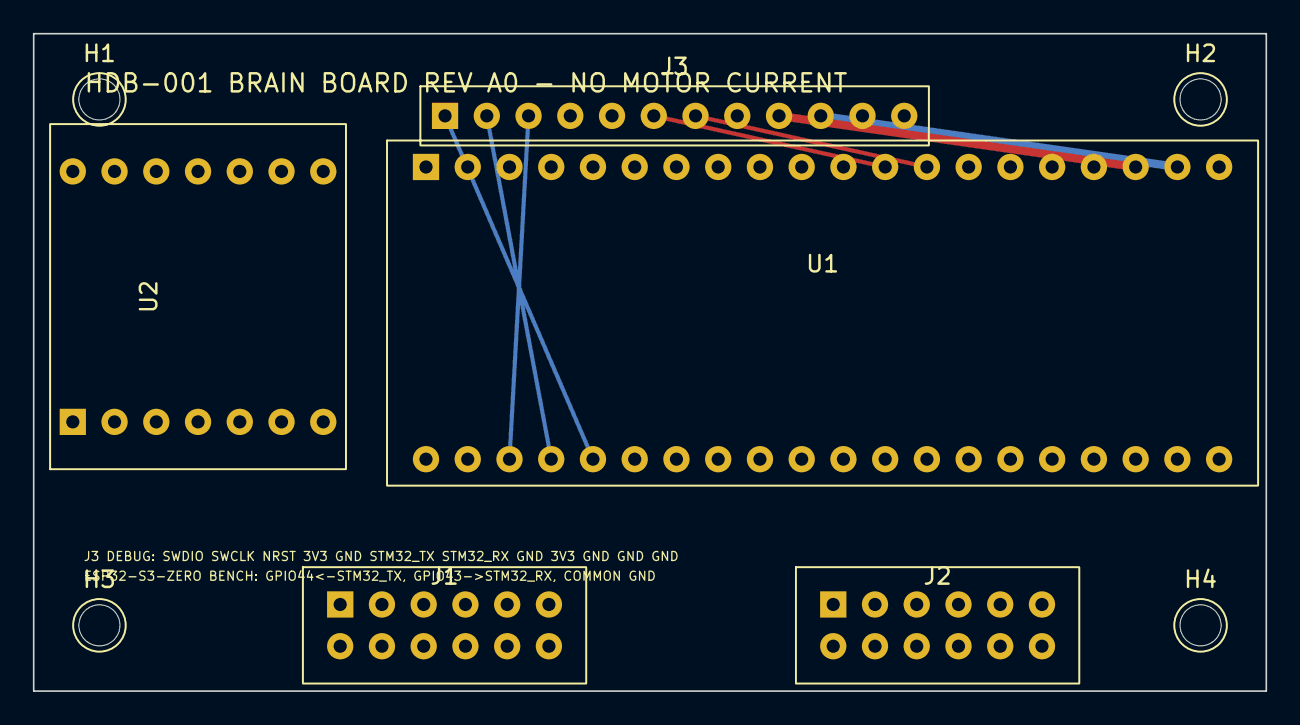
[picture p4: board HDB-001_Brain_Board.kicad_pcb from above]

Board: 2 copper layers, 75.0 x 40.0 mm, 9 parts (0 on the bottom side), 25 nets.

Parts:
H1, H2, H3, H4: M2.5; MountingHole_2p5_NPTH
J1: B2B Sensors/Logic; B2B_2x6_2p54
J2: B2B Commands/Power; B2B_2x6_2p54
J3: SWD/UART/Status placeholder; PinHeader_1x12_2p54
U1: Black Pill STM32F411CEU6; BlackPill_STM32F411_53x21
U2: XIAO ESP32-S3/Plus TBD; XIAO_ESP32S3_21x18

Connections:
3V3: J1.1, J3.4, J3.9, U1.18, U1.22
A0: J1.3, U1.3
A1: J1.4, U1.4
A2: J1.5, U1.5
A3: J1.6, U1.6
A4: J1.7, U1.7
A5: J1.8, U1.8
A6: J1.9, U1.9
A7: J1.10, U1.10
AIN1: J2.6, U1.25
AIN2: J2.7, U1.26
BIN1: J2.9, U1.27
BIN2: J2.10, U1.28
FAN_PWM: J2.12, U1.11
GND: J1.2, J2.2, J2.4, J3.5, J3.8, J3.10, J3.11, J3.12, U1.19, U1.21
LAT_L: J1.11, U1.30
LAT_R: J1.12, U1.31
NRST: J3.3, U1.38
PWMA: J2.5, U1.23
PWMB: J2.8, U1.24
STBY: J2.11, U1.29
STM32_RX: J3.7, U1.13
STM32_TX: J3.6, U1.12
SWCLK: J3.2, U1.37
SWDIO: J3.1, U1.36

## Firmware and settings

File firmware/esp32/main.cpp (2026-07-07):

#include <Arduino.h>
#include <WiFi.h>
#include "app_config.h"
#include "board_pins.h"
#include "communication/packet_parser.h"
#include "communication/uart_protocol.h"
#include "config/config_manager.h"
#include "safety/stm32_watchdog.h"
#include "telemetry/logger.h"
#include "telemetry/telemetry_model.h"
#include "web/web_server.h"

QueueHandle_t telemetry_queue = nullptr;
QueueHandle_t command_queue = nullptr;
QueueHandle_t event_queue = nullptr;
QueueHandle_t log_queue = nullptr;

static HardwareSerial Stm32Serial(STM32_UART_NUM);
static pegasus_telemetry_t telemetry;
static pegasus_config_t config;
static run_summary_t run_summary;
static bool uart_enabled = false;

static void apply_link_response(const pegasus::Packet &packet) {
    const uint32_t now = millis();
    const uint8_t about = packet.len > 0 ? packet.payload[0] : 0;
    const uint8_t reason = packet.len > 1 ? packet.payload[1] : 0;

    if (packet.type == pegasus::MSG_ACK) {
        telemetry.last_ack_type = about;
        telemetry.ack_count++;
        if (telemetry.command_pending && telemetry.pending_command_type == about) {
            telemetry.command_pending = false;
            telemetry.last_command_rtt_ms = now - telemetry.command_sent_ms;
        }
    } else if (packet.type == pegasus::MSG_NACK) {
        telemetry.last_nack_type = about;
        telemetry.last_nack_reason = reason;
        telemetry.nack_count++;
        if (telemetry.command_pending && telemetry.pending_command_type == about) {
            telemetry.command_pending = false;
            telemetry.last_command_rtt_ms = now - telemetry.command_sent_ms;
        }
    } else if (packet.type == pegasus::MSG_PONG) {
        telemetry.pong_count++;
        if (telemetry.command_pending && telemetry.pending_command_type == pegasus::MSG_PING) {
            telemetry.command_pending = false;
            telemetry.last_command_rtt_ms = now - telemetry.command_sent_ms;
        }
    }
}

static uint8_t command_type(pegasus_command_kind_t kind) {
    using namespace pegasus;
    switch (kind) {
    case CMD_SET_PID: return MSG_SET_PID;
    case CMD_SET_MOTOR_CONFIG: return MSG_SET_MOTOR_CONFIG;
    case CMD_SET_FAN_CONFIG: return MSG_SET_FAN_CONFIG;
    case CMD_CALIBRATION_START: return MSG_CALIBRATION_START;
    case CMD_CALIBRATION_STOP: return MSG_CALIBRATION_STOP;
    case CMD_ARM: return MSG_ARM;
    case CMD_DISARM: return MSG_DISARM;
    case CMD_START_RUN: return MSG_START_RUN;
    case CMD_STOP_RUN: return MSG_STOP_RUN;
    case CMD_HARDWARE_TEST: return MSG_HARDWARE_TEST;
    case CMD_PING: return MSG_PING;
    }
    return MSG_NACK;
}

static void uart_rx_task(void *) {
    pegasus::PacketParser parser;
    pegasus::Packet packet;
    for (;;) {
        if (!uart_enabled) {
            vTaskDelay(pdMS_TO_TICKS(100));
            continue;
        }
        while (Stm32Serial.available() > 0) {
            if (parser.push(static_cast<uint8_t>(Stm32Serial.read()), packet)) {
                if (packet.type == pegasus::MSG_ACK || packet.type == pegasus::MSG_NACK || packet.type == pegasus::MSG_PONG) {
                    apply_link_response(packet);
                } else {
                    telemetry_apply_packet(packet.type, packet.payload, packet.len, telemetry);
                }
                stm32_watchdog.mark_packet(millis());
                xQueueSend(telemetry_queue, &telemetry, 0);
                if (packet.type == pegasus::MSG_TELEMETRY_BASIC) {
                    logger_add_sample(run_summary, telemetry);
                }
            }
        }
        vTaskDelay(pdMS_TO_TICKS(2));
    }
}

static void uart_tx_task(void *) {
    pegasus_command_t cmd{};
    for (;;) {
        if (xQueueReceive(command_queue, &cmd, portMAX_DELAY) == pdTRUE) {
            if (uart_enabled) {
                const uint8_t type = command_type(cmd.kind);
                if (pegasus::write_packet(Stm32Serial, type, cmd.payload, cmd.len)) {
                    telemetry.pending_command_type = type;
                    telemetry.command_pending = true;
                    telemetry.command_sent_ms = millis();
                }
            }
        }
    }
}

static void stm32_watchdog_task(void *) {
    for (;;) {
        stm32_watchdog.apply(telemetry, millis());
        vTaskDelay(pdMS_TO_TICKS(100));
    }
}

static void wifi_manager_task(void *) {
    WiFi.mode(WIFI_AP);
    WiFi.softAP(PEGASUS_AP_SSID, PEGASUS_AP_PASS);
    for (;;) {
        vTaskDelay(pdMS_TO_TICKS(1000));
    }
}

static void web_server_task(void *) {
    web_server_begin(telemetry, config, run_summary);
    for (;;) {
        web_server_loop();
        vTaskDelay(pdMS_TO_TICKS(5));
    }
}

static void logger_task(void *) {
    for (;;) {
        vTaskDelay(pdMS_TO_TICKS(1000));
    }
}

static void analyzer_task(void *) {
    for (;;) {
        vTaskDelay(pdMS_TO_TICKS(2000));
    }
}

static void profile_manager_task(void *) {
    for (;;) {
        vTaskDelay(pdMS_TO_TICKS(5000));
    }
}

void setup() {
    Serial.begin(115200);
    delay(200);
    Serial.printf("PEGASUS ESP32 Rev A0 on %s\n", BOARD_NAME);

    telemetry_queue = xQueueCreate(PEGASUS_TELEMETRY_QUEUE_LEN, sizeof(pegasus_telemetry_t));
    command_queue = xQueueCreate(PEGASUS_COMMAND_QUEUE_LEN, sizeof(pegasus_command_t));
    event_queue = xQueueCreate(PEGASUS_EVENT_QUEUE_LEN, sizeof(uint32_t));
    log_queue = xQueueCreate(PEGASUS_LOG_QUEUE_LEN, sizeof(pegasus_telemetry_t));

    load_config(config);
    logger_reset(run_summary);

#if STM32_UART_TX_PIN >= 0 && STM32_UART_RX_PIN >= 0
    Stm32Serial.begin(PEGASUS_UART_BAUD, SERIAL_8N1, STM32_UART_RX_PIN, STM32_UART_TX_PIN);
    uart_enabled = true;
#else
    Serial.println("STM32 UART pins are TODO; running dashboard in no-UART mode.");
    uart_enabled = false;
#endif

    xTaskCreatePinnedToCore(uart_rx_task, "uart_rx", 4096, nullptr, 4, nullptr, 0);
    xTaskCreatePinnedToCore(uart_tx_task, "uart_tx", 4096, nullptr, 4, nullptr, 0);
    xTaskCreatePinnedToCore(stm32_watchdog_task, "stm32_wd", 2048, nullptr, 2, nullptr, 0);
    xTaskCreatePinnedToCore(wifi_manager_task, "wifi", 3072, nullptr, 2, nullptr, 0);

    xTaskCreatePinnedToCore(web_server_task, "web", 8192, nullptr, 2, nullptr, 1);
    xTaskCreatePinnedToCore(logger_task, "logger", 3072, nullptr, 1, nullptr, 1);
    xTaskCreatePinnedToCore(analyzer_task, "analyzer", 3072, nullptr, 1, nullptr, 1);
    xTaskCreatePinnedToCore(profile_manager_task, "profiles", 3072, nullptr, 1, nullptr, 1);
}

void loop() {
    vTaskDelay(pdMS_TO_TICKS(1000));
}

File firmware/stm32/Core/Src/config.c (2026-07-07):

#include "config.h"
#include <string.h>

#define PEGASUS_CONFIG_VERSION 0xA0000001u
#define PEGASUS_PWM_LIMIT 1000
#define PEGASUS_FAN_DELAY_LIMIT_MS 5000u

static float clamp_float(float value, float lo, float hi) {
    if (value != value) return lo;
    if (value < lo) return lo;
    if (value > hi) return hi;
    return value;
}

static int16_t clamp_i16(int16_t value, int16_t lo, int16_t hi) {
    if (value < lo) return lo;
    if (value > hi) return hi;
    return value;
}

static uint16_t clamp_u16(uint16_t value, uint16_t hi) {
    return value > hi ? hi : value;
}

robot_config_t robot_default_config(void) {
    robot_config_t c;
    memset(&c, 0, sizeof(c));
    c.kp = 0.55f;
    c.ki = 0.0f;
    c.kd = 0.10f;
    c.integral_limit = 500.0f;
    c.derivative_filter = 0.65f;
    for (uint8_t i = 0; i < 8; ++i) {
        c.sensor_threshold[i] = 350;
        c.sensor_strong_threshold[i] = 700;
    }
    c.lat_l_threshold = 500;
    c.lat_r_threshold = 500;
    c.crossing_sum_threshold = 3500;
    c.crossing_min_count = 5;
    c.crossing_min_span = 5;
    c.lost_line_sum_threshold = 250;
    c.base_speed = 350;
    c.pwm_min_left = 120;
    c.pwm_min_right = 120;
    c.pwm_max_left = 750;
    c.pwm_max_right = 750;
    c.accel_limit = 25;
    c.brake_limit = 60;
    c.left_motor_inverted = false;
    c.right_motor_inverted = false;
    c.fan_pwm_start = 300;
    c.fan_pwm_run = 500;
    c.fan_pwm_max = 800;
    c.fan_start_delay_ms = 400;
    c.fan_mode = FAN_MODE_OFF;
    c.finish_min_run_time_ms = 3000;
    c.line_lost_timeout_ms = 80;
    c.crossing_debounce_ms = 30;
    c.lateral_debounce_ms = 50;
    c.lateral_lockout_after_crossing_ms = 100;
    c.stop_on_esp_timeout = false;
    robot_config_finalize(&c);
    return c;
}

uint32_t robot_config_checksum(const robot_config_t *config) {
    robot_config_t copy = *config;
    copy.checksum = 0;
    const uint8_t *bytes = (const uint8_t *)&copy;
    uint32_t sum = 2166136261u;
    for (uint32_t i = 0; i < sizeof(copy); ++i) {
        sum ^= bytes[i];
        sum *= 16777619u;
    }
    return sum;
}

bool robot_config_valid(const robot_config_t *config) {
    return config->config_version == PEGASUS_CONFIG_VERSION &&
           config->checksum == robot_config_checksum(config);
}

void robot_config_finalize(robot_config_t *config) {
    config->kp = clamp_float(config->kp, 0.0f, 20.0f);
    config->ki = clamp_float(config->ki, 0.0f, 10.0f);
    config->kd = clamp_float(config->kd, 0.0f, 20.0f);
    config->integral_limit = clamp_float(config->integral_limit, 0.0f, 5000.0f);
    config->derivative_filter = clamp_float(config->derivative_filter, 0.0f, 1.0f);

    config->base_speed = clamp_i16(config->base_speed, -PEGASUS_PWM_LIMIT, PEGASUS_PWM_LIMIT);
    config->pwm_min_left = clamp_i16(config->pwm_min_left, 0, PEGASUS_PWM_LIMIT);
    config->pwm_min_right = clamp_i16(config->pwm_min_right, 0, PEGASUS_PWM_LIMIT);
    config->pwm_max_left = clamp_i16(config->pwm_max_left, 0, PEGASUS_PWM_LIMIT);
    config->pwm_max_right = clamp_i16(config->pwm_max_right, 0, PEGASUS_PWM_LIMIT);
    if (config->pwm_min_left > config->pwm_max_left) config->pwm_min_left = config->pwm_max_left;
    if (config->pwm_min_right > config->pwm_max_right) config->pwm_min_right = config->pwm_max_right;

    config->fan_pwm_max = clamp_u16(config->fan_pwm_max, PEGASUS_PWM_LIMIT);
    config->fan_pwm_start = clamp_u16(config->fan_pwm_start, config->fan_pwm_max);
    config->fan_pwm_run = clamp_u16(config->fan_pwm_run, config->fan_pwm_max);
    config->fan_start_delay_ms = clamp_u16(config->fan_start_delay_ms, PEGASUS_FAN_DELAY_LIMIT_MS);
    if (config->fan_mode > FAN_MODE_ESC_SERVO) config->fan_mode = FAN_MODE_OFF;

    config->config_version = PEGASUS_CONFIG_VERSION;
    config->checksum = 0;
    config->checksum = robot_config_checksum(config);
}

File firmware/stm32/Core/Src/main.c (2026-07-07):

#include "main.h"
#include "config.h"
#include "pegasus_hal.h"
#include "robot_state.h"
#include "telemetry.h"
#include "uart_protocol.h"
#include <string.h>

static robot_context_t g_robot;
static pegasus_parser_t g_parser;

static void send_simple(uint8_t type, uint8_t about_type) {
    uint8_t payload[2] = {about_type, 0};
    uint8_t frame[PEGASUS_UART_MAX_PAYLOAD + 4u];
    size_t len = 0;
    if (pegasus_encode_packet(type, payload, sizeof(payload), frame, sizeof(frame), &len)) {
        pegasus_hal_uart_write(frame, (uint16_t)len);
    }
}

static float read_float_le(const uint8_t *p) {
    float v;
    memcpy(&v, p, sizeof(float));
    return v;
}

static int16_t read_i16_le(const uint8_t *p) {
    return (int16_t)((uint16_t)p[0] | ((uint16_t)p[1] << 8));
}

static uint16_t read_u16_le(const uint8_t *p) {
    return (uint16_t)((uint16_t)p[0] | ((uint16_t)p[1] << 8));
}

static bool require_empty_payload(const pegasus_packet_t *packet) {
    if (packet->len == 0) {
        return true;
    }
    send_simple(MSG_NACK, packet->type);
    return false;
}

static void handle_packet(const pegasus_packet_t *packet) {
    g_robot.last_esp_packet_ms = pegasus_hal_millis();
    g_robot.esp_online = true;

    switch (packet->type) {
    case MSG_SET_PID:
        if (packet->len == 12) {
            g_robot.config.kp = read_float_le(&packet->payload[0]);
            g_robot.config.ki = read_float_le(&packet->payload[4]);
            g_robot.config.kd = read_float_le(&packet->payload[8]);
            robot_config_finalize(&g_robot.config);
            send_simple(MSG_ACK, packet->type);
        } else {
            send_simple(MSG_NACK, packet->type);
        }
        break;
    case MSG_SET_MOTOR_CONFIG:
        if (packet->len == 10) {
            g_robot.config.base_speed = read_i16_le(&packet->payload[0]);
            g_robot.config.pwm_min_left = read_i16_le(&packet->payload[2]);
            g_robot.config.pwm_min_right = read_i16_le(&packet->payload[4]);
            g_robot.config.pwm_max_left = read_i16_le(&packet->payload[6]);
            g_robot.config.pwm_max_right = read_i16_le(&packet->payload[8]);
            robot_config_finalize(&g_robot.config);
            send_simple(MSG_ACK, packet->type);
        } else {
            send_simple(MSG_NACK, packet->type);
        }
        break;
    case MSG_SET_FAN_CONFIG:
        if (packet->len == 9) {
            g_robot.config.fan_pwm_start = read_u16_le(&packet->payload[0]);
            g_robot.config.fan_pwm_run = read_u16_le(&packet->payload[2]);
            g_robot.config.fan_pwm_max = read_u16_le(&packet->payload[4]);
            g_robot.config.fan_start_delay_ms = read_u16_le(&packet->payload[6]);
            g_robot.config.fan_mode = packet->payload[8];
            robot_config_finalize(&g_robot.config);
            send_simple(MSG_ACK, packet->type);
        } else {
            send_simple(MSG_NACK, packet->type);
        }
        break;
    case MSG_CALIBRATION_START:
        if (!require_empty_payload(packet)) break;
        if (g_robot.state == ST_IDLE || g_robot.state == ST_READY) {
            robot_begin_calibration(&g_robot, pegasus_hal_millis());
            send_simple(MSG_ACK, packet->type);
        } else {
            send_simple(MSG_NACK, packet->type);
        }
        break;
    case MSG_CALIBRATION_STOP:
        if (!require_empty_payload(packet)) break;
        if (g_robot.state == ST_CALIBRATION) {
            robot_finish_calibration(&g_robot, pegasus_hal_millis());
            send_simple(MSG_ACK, packet->type);
        } else {
            send_simple(MSG_NACK, packet->type);
        }
        break;
    case MSG_ARM:
        if (!require_empty_payload(packet)) break;
        send_simple(robot_request_arm(&g_robot) ? MSG_ACK : MSG_NACK, packet->type);
        break;
    case MSG_DISARM:
        if (!require_empty_payload(packet)) break;
        send_simple(robot_request_disarm(&g_robot) ? MSG_ACK : MSG_NACK, packet->type);
        break;
    case MSG_START_RUN:
        if (!require_empty_payload(packet)) break;
        send_simple(robot_request_start(&g_robot) ? MSG_ACK : MSG_NACK, packet->type);
        break;
    case MSG_STOP_RUN:
        if (!require_empty_payload(packet)) break;
        robot_request_stop(&g_robot);
        send_simple(MSG_ACK, packet->type);
        break;
    case MSG_HARDWARE_TEST:
        if (!require_empty_payload(packet)) break;
        if (robot_request_hardware_test(&g_robot, pegasus_hal_millis())) {
            send_simple(MSG_ACK, packet->type);
        } else {
            send_simple(MSG_NACK, packet->type);
        }
        break;
    case MSG_PING:
        if (!require_empty_payload(packet)) break;
        send_simple(MSG_PONG, packet->type);
        break;
    default:
        send_simple(MSG_NACK, packet->type);
        break;
    }
}

void pegasus_app_init(void) {
    pegasus_hal_init();
    robot_init(&g_robot);
    pegasus_parser_init(&g_parser);
}

void pegasus_app_loop(void) {
    uint8_t byte = 0;
    pegasus_packet_t packet;

    while (pegasus_hal_uart_read_byte(&byte)) {
        if (pegasus_parser_push(&g_parser, byte, &packet)) {
            handle_packet(&packet);
        }
    }

    if (pegasus_hal_control_tick_due()) {
        const uint32_t now = pegasus_hal_millis();
        robot_control_tick(&g_robot, now);
        telemetry_send_periodic(&g_robot, robot_motor_state(), robot_fan_state(), now);
        pegasus_hal_watchdog_refresh();
    }
}

int main(void) {
    pegasus_app_init();
    while (1) {
        pegasus_app_loop();
    }
}

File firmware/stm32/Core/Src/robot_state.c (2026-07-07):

#include "robot_state.h"
#include "board_pins.h"
#include "calibration.h"
#include "line_detector.h"
#include "pegasus_hal.h"
#include "pid_controller.h"
#include "safety.h"
#include <string.h>

static motor_state_t g_motor;
static fan_state_t g_fan;
static pid_controller_t g_pid;
static line_detector_t g_line_detector;
static calibration_state_t g_calibration;

static uint32_t state_age(const robot_context_t *ctx, uint32_t now_ms) {
    return now_ms - ctx->state_enter_ms;
}

const motor_state_t *robot_motor_state(void) {
    return &g_motor;
}

const fan_state_t *robot_fan_state(void) {
    return &g_fan;
}

void robot_set_state(robot_context_t *ctx, robot_state_t state, uint32_t now_ms) {
    if (ctx->state == state) return;
    ctx->state = state;
    ctx->state_enter_ms = now_ms;
}

void robot_request_stop(robot_context_t *ctx) {
    ctx->arm_requested = false;
    ctx->start_requested = false;
    ctx->disarm_requested = false;
    ctx->stop_requested = true;
}

bool robot_request_arm(robot_context_t *ctx) {
    if (ctx->state != ST_IDLE && ctx->state != ST_READY) {
        return false;
    }
    ctx->arm_requested = true;
    return true;
}

bool robot_request_disarm(robot_context_t *ctx) {
    if (ctx->state != ST_ARMED && ctx->state != ST_SAFE_STOP) {
        return false;
    }
    ctx->disarm_requested = true;
    return true;
}

bool robot_request_start(robot_context_t *ctx) {
    if (ctx->state != ST_ARMED) {
        return false;
    }
    ctx->start_requested = true;
    return true;
}

bool robot_request_hardware_test(robot_context_t *ctx, uint32_t now_ms) {
    if (ctx->state != ST_IDLE && ctx->state != ST_READY) {
        return false;
    }
    robot_set_state(ctx, ST_HARDWARE_TEST, now_ms);
    return true;
}

void robot_begin_calibration(robot_context_t *ctx, uint32_t now_ms) {
    calibration_begin(&g_calibration, &ctx->sensors, now_ms);
    robot_set_state(ctx, ST_CALIBRATION, now_ms);
}

void robot_finish_calibration(robot_context_t *ctx, uint32_t now_ms) {
    if (calibration_finish(&g_calibration, &ctx->sensors)) {
        robot_set_state(ctx, ST_READY, now_ms);
    } else {
        ctx->error_flags |= ERR_SENSOR_FAULT;
        robot_set_state(ctx, ST_ERROR, now_ms);
    }
}

void robot_init(robot_context_t *ctx) {
    memset(ctx, 0, sizeof(*ctx));
    ctx->state = ST_BOOT;
    ctx->config = robot_default_config();
    sensor_state_init(&ctx->sensors);
    motor_init(&g_motor);
    fan_init(&g_fan);
    pid_init(&g_pid);
    line_detector_init(&g_line_detector);
}

static void update_sensors(robot_context_t *ctx, uint32_t dt_ms) {
    uint16_t adc[PEGASUS_SENSOR_TOTAL_COUNT] = {0};
    pegasus_hal_get_adc_snapshot(adc, PEGASUS_SENSOR_TOTAL_COUNT);
    sensor_set_raw_from_adc(&ctx->sensors, adc, PEGASUS_SENSOR_TOTAL_COUNT);
    sensor_filter(&ctx->sensors, 3, 10);
    sensor_normalize(&ctx->sensors, &ctx->config, false);
    sensor_extract_features(&ctx->sensors, &ctx->config, dt_ms);
}

static void run_line_control(robot_context_t *ctx, uint32_t dt_ms, bool freeze_integral) {
    const float dt_s = (float)dt_ms / 1000.0f;
    const float correction = pid_update(&g_pid, &ctx->config, (float)ctx->sensors.error, dt_s, freeze_integral);
    motor_set_targets_from_pid(&g_motor, &ctx->config, correction);
    motor_apply(&g_motor, &ctx->config);
}

static void safe_outputs(void) {
    motor_stop_brake(&g_motor);
    fan_off(&g_fan);
    pid_reset(&g_pid);
}

void robot_control_tick(robot_context_t *ctx, uint32_t now_ms) {
    uint32_t dt_ms = now_ms - ctx->last_control_ms;
    if (dt_ms == 0 || dt_ms > 100) dt_ms = 1000u / PEGASUS_CONTROL_HZ;
    ctx->last_control_ms = now_ms;

    update_sensors(ctx, dt_ms);
    line_detector_update(&g_line_detector, &ctx->sensors, &ctx->config, now_ms, dt_ms);

    if (ctx->stop_requested || safety_has_critical_fault(ctx, now_ms)) {
        robot_set_state(ctx, ST_SAFE_STOP, now_ms);
        ctx->stop_requested = false;
    }
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

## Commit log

2026-07-04 Initial PEGASUS Rev A0 KiCad project
    [HDB-001_Brain_Board.kicad_pcb, HDB-001_Brain_Board.kicad_sch, HDB-100_Chassis_Power_Board.kicad_pcb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]
2026-07-05 Add Rev A0 firmware and STM32 state machine docs
2026-07-07 Advance Rev A0 cockpit firmware and PCB bring-up
    [HDB-001_Brain_Board.kicad_pcb, HDB-101_Sensor_Board.kicad_pcb]
2026-07-07 Track UART command acknowledgements on ESP32
2026-07-07 Add STM32 F411 firmware build scripts
2026-07-07 Test fake STM32 command contract
2026-07-09 Advance HDB-100 offline KiCad assembly
    [HDB-100_Chassis_Power_Board.kicad_pcb]
